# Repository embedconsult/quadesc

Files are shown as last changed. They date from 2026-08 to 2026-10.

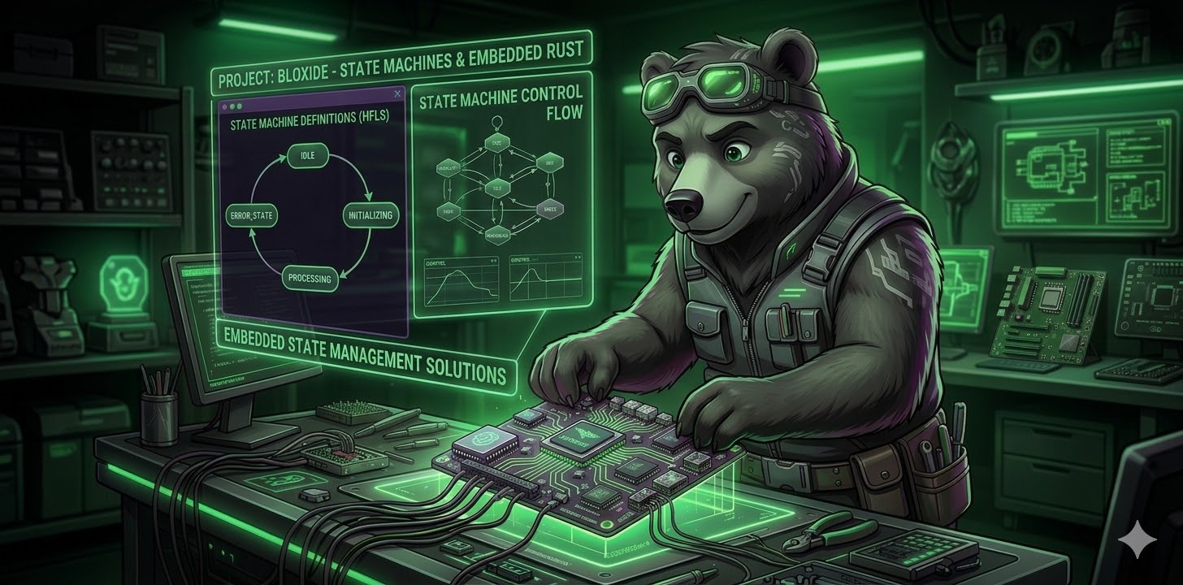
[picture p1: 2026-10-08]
firmware/source/inputs/bloxide/bloxide.jpg

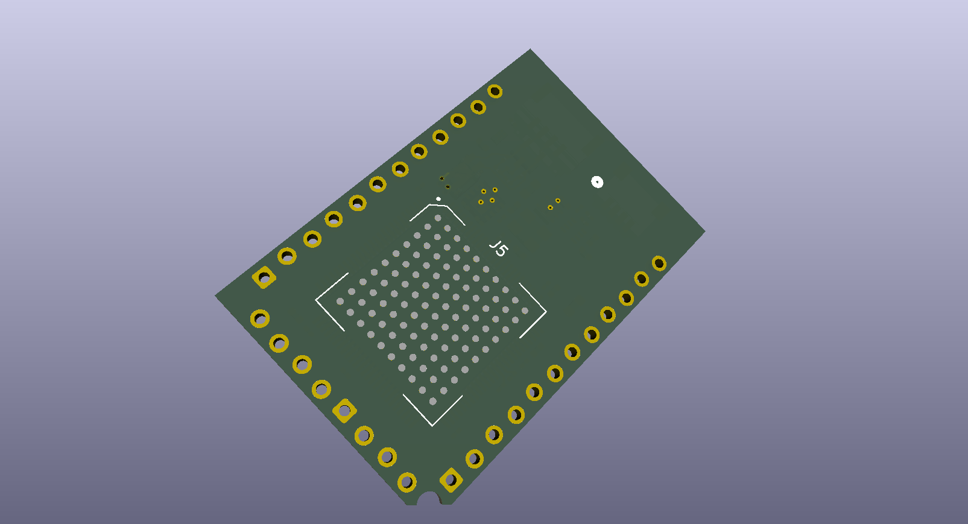
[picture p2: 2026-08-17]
som/som_bottom.png

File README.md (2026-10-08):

# QuadESC

QuadESC is a four-motor power board with an installed AM13E system-on-module. This repository contains the editable mainboard and module designs, schematics, firmware sources and hardware manuals.

## Hardware documentation

The handoff manuals are maintained as Markdown in [`documentation/source/`](documentation/source/):

- [QuadESC manual](documentation/source/quadesc/index.md): power, connections, sensing, control resources and mechanical integration.
- [AM13E SoM manual](documentation/source/som/index.md): module interfaces, pin assignments, power selection, TI BSL programming and debug.

Connector references retain pin numbers, net names and electrical mappings. Use the KiCad designs for physical board geometry.

See [documentation build instructions](documentation/README.md) to generate the HTML site locally. CI builds and checks the same source for merge requests and pull requests, and publishes the manuals from `main` through GitHub Pages on [embedconsult/quadesc](https://github.com/embedconsult/quadesc), with an optional GitLab Pages pipeline for OpenBeagle. Generated HTML is a CI artifact rather than checked-in content.

## Repository layout

| Path | Contents |
| --- | --- |
| `mainboard/` | Editable QuadESC mainboard design |
| `som/` | Editable AM13E module design |
| `mainboard_schematic.pdf`, `som_schematic.pdf` | Exported schematics |
| `documentation/source/` | Markdown manuals, shared diagrams and styling |
| `documentation/reference/` | Electrical connector, GPIO and analog reference data |
| `tools/documentation/` | Documentation build and validation scripts |
| `firmware/` | Firmware sources and existing application/loader artifacts |
| `drone-flasher-swd/` | SWD programming utility |

Documentation builds use only the manuals and their reference assets. See the [programming guide](documentation/source/som/firmware.md) for module programming interfaces.

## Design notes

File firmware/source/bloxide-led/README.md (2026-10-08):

# Bloxide LED host precursor

The separate host XCP demo composes this generated LED Owner with the generated XCP Session. Its additive `XcpProvider` action translates typed requests into the existing sole Owner, retained outcomes and output admission; it does not select Profile P or SAVE. The frozen Apply/Read/Release scalar interface remains intact.

This private feature package contains plain LED messages, validated scalar values, the portable calibration owner action context, a split-once output slot, absolute-time phase calculation, and a pure TOML `led-owner` blox. It reuses the pinned `bloxide-calibration` `Owner`, `CommitGate`, and `OperationKey` source supplied by this diagnostic hub. The local Cargo path dependency is explicit for this bounded composition; a releasable independent package still needs a reviewed source distribution choice.

Only `LedController::apply` changes the active configuration. A changed value reserves the output slot before the T07 owner commits and publishes an `OutputSchedule` before the retained Applied result is visible. A same-value operation does not reserve a slot or reset phase/revision. The split producer and consumer are moved to distinct owners; no actor Reset splits the slot again. `phase_at` computes the current logical phase from an absolute epoch, including late polls and constant duty extremes.

The output slot supports one queued schedule, one service-owned schedule and two retained dispositions. Quiescence closes admission and retires a queued schedule with a disposition; an explicit consumer acknowledgement opens a requested new output epoch. Host tests cover this path. Physical GPIO completion, electrical state, timing and fault recovery remain target integration obligations.

Source files here are authored for this precursor. No license is asserted for this new repository. The framework and calibration inputs retain their own source notices and are not copied into it.

For the hosted diagnostic, a second split-once bounded reply slot passes typed action outcomes to the serial service. An occupied reply remains intact and latches overflow instead of overwriting a result; the serial session stops admission if that invariant fails.

This integration branch adds a selected restricted Profile P action and a UART SAVE action to the same declarative `led-owner` blox. `LedController` still contains the sole calibration `Owner<LedConfig>`. Profile P borrows that Owner only inside the generated action; scalar writes use the existing validated apply path and output reservation. A fixed `ProfileSlot` holds the reviewed protocol/service/Broker state, while the application pumps backend commands outside the action. A host-only simulator supplies media for source tests. Without an attached slot, SAVE is unavailable and Profile P is fenced, including in the selected AM13 target composition. No fault recovery control was added.

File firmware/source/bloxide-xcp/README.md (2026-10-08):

# bloxide-xcp

The drone board composition in `../drone-esc-firmware/examples/am13-xcp-control/system.toml` selects this package's CLI-generated Session actor. Ready/connection/recovery/waiting leaves route packets declaratively, and fixed bridge slots carry owned provider commands and complete responses. The independent S0 packet/core/SxI libraries remain reusable and no generated Rust is edited in source.

Reusable transport-neutral XCP protocol surfaces for Bloxide applications.
The implemented `0.1.0` cut is the deliberately narrow scalar S0 profile:
XCP 1.0/SxI 1.0 identifiers, CTO/DTO 8, little-endian byte addressing, and
only CONNECT, DISCONNECT, GET_STATUS, SYNCH, SET_MTA, UPLOAD, and DOWNLOAD.

This is a scoped interoperability profile, not a full ASAM XCP conformity
claim. DAQ, pages, STIM, programming, security, block mode, discovery, CAN
framing, and A2L IF_DATA are not implemented or advertised.

## Packages

- `xcp-messages`: fixed-size plain packet and provider-completion data.
- `xcp-core`: `no_std`, allocation-free codec/session/map/provider boundary.
- `xcp-sxi`: `no_std`, allocation-free LEN8/CTR8/SUM8 codec, explicit-idle
  parser and bounded Session adapter.
- `blox-ctx-xcp`: synchronous context actions with one retained effect and
  one retained response slot.
- `bloxes/session/blox.toml`: pure declarative broker topology; generated Rust
  remains build output.
- `fixtures/generated-session`: real concrete generated actions and lifecycle/
  correlation/saturation regressions against pinned Bloxide, plus a mock endpoint.
- `fixtures/standalone-consumer`: unrelated thermostat-style downstream
  consumer proving the core has no drone, LED, AM13, runtime, or HAL coupling.
- `fixtures/sxi-endpoint`: host-only real Session/SxI endpoint with a bounded
  deterministic provider fake for PTY qualification.
- `interop`: accepted T10 owned synchronous pyXCP transport plus the T34 product
  endpoint runner. The integrated T10 subtree identity is locked in
  `integration-lock.json`.

The checked virtual map resolves logical addresses to descriptor IDs and
offsets. It never turns a client address into a Rust pointer. DOWNLOAD emits
an owned provider request and responds positively only after the provider
reports the canonical owner outcome as Applied. Retired, stale, lost, or
uncertain outcomes fence the session rather than fabricate a rejection.

See [spec/xcp-s0.md](spec/xcp-s0.md) for exact PDUs and invariants and
[application source overview](../drone-esc-firmware/README.md) for the current integration boundaries.

## SxI ownership and scheduling

Construct the adapter once with `xcp_sxi::with_adapter(|adapter| ...)` and move
it into its owning service inside that scope. Lease lifetimes belong to that
instance; completion consumes the opaque token. Check `lease_is_current` before
bounded emission, then `complete_tx`. Use `lifecycle_fence` for Stop/Reset, retaining
Session truth and resources. There is no clone/default/reconstruction API.

Core `Session::service` returns `ServiceResult` with durable dispatch and per-call
new-fault provenance; SxI uses both to revoke partial input on fresh provider
failure while preserving Busy progress.

Call `service` at bounded control opportunities even under RX/TX pressure; supply
monotonic timestamps to parser polling and pre-arrival feeding. Late suffixes
expire before timestamp refresh at >=20ms. `observe_idle(now, provider)` is the
explicit recovery operation and durably fences clock faults. See
[spec/sxi-s0.md](spec/sxi-s0.md) for the complete scheduler and ownership contract.

## Development

Rust 1.94.0 is pinned by `rust-toolchain.toml`.

```sh
CARGO_BUILD_JOBS=2 cargo test --workspace --locked
CARGO_BUILD_JOBS=2 cargo clippy --workspace --all-targets --locked -- -D warnings
CARGO_BUILD_JOBS=2 cargo check -p xcp-core -p xcp-sxi \
  --target thumbv8m.main-none-eabi --locked
CARGO_BUILD_JOBS=2 cargo test \
  --manifest-path fixtures/standalone-consumer/Cargo.toml --locked
CARGO_BUILD_JOBS=2 cargo test \
  --manifest-path fixtures/generated-session/Cargo.toml --locked
CARGO_BUILD_JOBS=2 cargo build \
  --manifest-path fixtures/sxi-endpoint/Cargo.toml --locked
```

The accepted Bloxide baseline `43c4faa...` can lint the source topology. Its
pre-package code generator requires framework crates and the codegen crate as
local paths inside the consumer workspace, so full external materialization
uses the package/composition work owned by T06. This repository does not copy
framework sources or commit generated Rust to work around that boundary.

Public reference pins used for the selected command/error layouts:

- pyXCP 0.29.18 commit
  [`016cf3e`](https://github.com/christoph2/pyxcp/tree/016cf3e44364e9cd93966d144a39d342578a0391)
- [ASAM XCP public overview](https://www.asam.net/standards/detail/mcd-1-xcp/wiki/)

The retained interoperability fixtures exercise protocol packet ownership and
framing independently of the hardware. Their source contracts do not constitute
electrical UART/CAN timing or ASAM conformance evidence. Current application and
host regression results are recorded in `firmware/build-report.json`.

## Restricted persistence profile P (reusable source)

[spec/profile-p.md](spec/profile-p.md) documents the separate reviewed single-page P adapter, its borrowed Owner/service seam, matched host PTY fixture and remaining generated/target gates. S0 remains unchanged; the P adapter is selected explicitly by composition.

The LED integration branch resolves this crate's path dependencies to the selected local framework `2b4ec83`, calibration `c0a693a` and persistence `5d67c99` inputs. `tools/check_profile_p_inputs.py` checks those local pins and unchanged copied metadata. The firmware's generated owner action supplies Profile P's synchronous `Domain` borrow; this crate still has no second LED owner and its S0 source is unchanged. The application uses its own image identity and concrete board calibration backend; see the customer engineering manual for that integration.

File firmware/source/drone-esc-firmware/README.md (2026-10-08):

# Drone board application source

This is the authored schema 7 application composition for the SoM and QuadESC.
The customer release contains 252 parameters and the CAN XCP demo selected by
[`examples/am13-xcp-control/system.toml`](examples/am13-xcp-control/system.toml).
The generated executable is `can-xcp-control-am13`, targeting
`thumbv8m.main-none-eabi` with the application origin at `0x8000`.

[`mcu-xcp-platform`](mcu-xcp-platform) owns hardware initialization, fixed transport
slots, driver/PWM control, calibration storage and lifecycle shutdown. The LED
owner, XCP Session actor and framework are supplied as local source dependencies.
[`characterization`](characterization) contains the portable driver, PWM, ADC and
thermal contracts; [`host-all-motor-regression`](host-all-motor-regression) tests
the concrete board adapter without operating hardware.

Startup leaves PWM and both enable controls inactive. Raw driver faults for all
four motors interlock bench operation. Failed GPIO-off confirmation exposes
`drv_enable_state_known=0` and fences actuation, SPI, SAVE and reboot; an explicit
disable command can retry in a live session. An uncertain lifecycle completion
fences the transport and requires external safe-off and deliberate recovery.
The engineering manual explains that distinction and the bounded bench workflow.

Build, test and artifact commands run from the handoff root:

```sh
bash tools/firmware/build.sh NEW_BUILD_DIRECTORY
bash tools/firmware/test.sh NEW_TEST_DIRECTORY
python3 -B tools/firmware/verify.py
```

The build uses the shipped locks without resolving newer dependency versions.
Authored Rust, TOML and generator sources are retained here. Generated Rust and
Cargo scaffolding are disposable build outputs; the delivered BIN, AB1, ELF,
A2L and JSON metadata are under [`firmware/application`](../../application).
Calibration storage and loader ABI1 retain their existing layouts. SAVE is
available for persisted LED/ADC calibration fields while shutdown is confirmed.

See the [firmware overview](../../README.md), [portable build instructions](../../../tools/firmware/README.md),
[CAN tools](../../../tools/can/README.md), [engineering manual](../../../documentation/html/engineering/index.html)
and [source provenance](../../source-provenance.json) for the complete customer workflow.

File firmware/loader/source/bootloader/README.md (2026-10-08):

# AM13 CAN-FD bootloader ABI1

Standalone Rust reset loader, hardware-qualified2026-09-25 on the attached SOM.
Evidence and limits are in `notes/can-xcp-bootloader-r1/RESULT.md`. Current reservation32KiB; application origin0x8000, capacity222KiB,
end0x3f800; metadata occupies its own2KiB sector, ending at bank boundary0x40000.
Bank1 remains reserved so the application's existing calibration writes stay in
the opposite flash bank. CAL_A0x78000/CAL_B0x7c000 and their guards are preserved.

`contract.json` specifies transport, memory map, header, commit marker and command
sequence. CPU32MHz SYSOSC; explicit25MHz crystal startup, PLL400MHz/20/2 gives
CAN10MHz;500kbps nominal20tq/80%,2Mbps data5tq/80%, TDC offset4mtq.
MCAN_ICLK16MHz>=MCAN_FCLK10MHz, as required by TI SPRUJF2B27.4.2.
Clock startup is bounded; crystal failure stays in loader with CAN unavailable;
SWD recovery remains available. No oscillator autodetection.

Loader IDs0x710/0x711 CAN-FD+BRS64byte CTO; normal app calibration remains
classic500kbps IDs0x700/0x701. GET_ID0 identifies
`AM13E23019-CANBOOT/0.1.0/ABI1`. Reset with BOOT low, then CONNECT within3seconds;
invalid app stays indefinitely, any CONNECT holds until reset. BOOT high selects
TI ROM, not this loader. No app cooperation is required for reset+connect entry.

Standard XCP PROGRAM commands/opcodes and pyXCP0.29.18 framing were checked
against primary local source. Stop-and-wait only: use `last=True` for PROGRAM.
No DAQ, block transfer, sector info, seed/key, signature, encryption or rollback
protection. CRC detects corruption; it is not authentication. Firmware version
is descriptive. Header board/layout/ABI/length/CRC and vectors are checked.

Header staging must precede erase; metadata is invalidated before application
sectors. Sequential image bytes buffer into16-byte ECC-safe program granules.
PROGRAM count0 verifies full CRC and vectors. PROGRAM_RESET verifies again,
writes header then separate commit marker last, ACKs and resets. SRAM MSP must
be within conservative96KiB range and aligned; Thumb reset PC must lie in image.
RAM flash/read routines avoid instruction fetches from busy flash; GSC ownership,
sector bounds, dynamic protection and status checks guard each operation.
Non-erased/partial metadata reads handle ECC from RAM; invalid CRC cannot boot.
No mass erase, NONMAIN write, fuse/debug lock, static write protection or motor
operation is implemented. Logical bounds exclude loader, metadata and calibration
from raw app programming. Metadata access is a constrained staged transaction.

Application reinitializes its clocks/interrupts. Handoff stops CAN/SysTick, masks
interrupts, disables/clears NVIC, sets VTOR0x8000 and validated MSP/Thumb PC,
clears CONTROL/BASEPRI/FAULTMASK/MSPLIM. IRQs remain masked until app startup.

One-time install is SWD, using checked target identity, sector-only writes and
full loader readback. UART bootstrap was not tested. No factory NONMAIN change
is required by this source. Current SOM still has the earlier ROM bootPLL fix;
a physical untouched-factory NONMAIN test has not been performed. ROM CAN IDs3/4,
1Mbps and its25MHz direct-clock limitation are separate from this custom loader.

CLKDIV must be written after CLKEN; target readback admission checks this.
Normal CAN controller automatic error retry is enabled, with bounded polling.

Build: `bash notes/can-xcp-bootloader-r1/build-loader.sh` and `build-app.sh` on
bloxide1, Rust1.94.0 target thumbv8m.main-none-eabi. `package.sh` produces
bootloader.bin,app.bin,app.ab1. Host tests: test-core.sh and test-driver.sh.
Deployment/updater scripts are under notes/can-xcp-bootloader-r1/hardware;
bootstrap procedure and hardware evidence are packaged separately.

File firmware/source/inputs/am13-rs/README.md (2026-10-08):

# am13-rs

Small all-Rust `no_std` AM13E23019 support extracted from the frozen corrected diagnostic firmware. This is chip support, not a complete PAC, an ESC application, or electrically qualified new firmware. SoM pin assignments live in `esc-som-board`. Current ADC, MCPWM, UC2 I²C, UC3 SPI and MCAN0 additions are described in [board peripheral drivers](spec/board-peripherals.md).

`Peripherals::take()` is a one-shot hardware acquisition that quiesces inherited IRQs. It yields independent clock, GPIO setup, UC4, ADC, MCPWM0–3, UC2 I²C, UC3 SPI, MCAN0 and SysTick owners. Handles remain non-Send/non-Sync and move into a single thread-mode executor; no legacy global MMIO reference or mutable actor backdoor is exposed. Drop never releases the singleton or reinitializes hardware.

Clocks select nominal 32MHz SYSOSC. `Clocks::uc4_hz()` correctly reports 32MHz with the MCLKDIV2 domain bypass; UART uses CLKSEL=8 and CLKDIV=0. `Uc4::configure` prepares 8N1 disabled, the board selects pads, and `enable` verifies readback. `Uart::try_read/try_write/is_tx_complete` do bounded register work; `embassy` adds embedded-io-async Read/Write with 100us timer retries and cancellation-safe single-byte admissions. TX admission waits for the previous byte’s EOT; flush includes the final stop bit and is independent of receive activity. See [TX completion and bounds](spec/uart-completion.md). GPIO outputs implement embedded-hal 1.0.0. Readback is register/pad evidence, never optical observation.

The `embassy` feature provides the real Embassy time driver and sole SysTick handler. It uses a coherent u64 10kHz counter and 16 fixed task/deadline slots. It validates Embassy task wakers and stores TaskRef, so no generic Waker clone/drop or timer allocation occurs. Cancelled timers can leave one earliest pending deadline per task until expiry and cause harmless early wakes. A seventeenth retained task deadline latches `time::capacity_faulted()` and panics; target integration must use an allocation-free halt handler. See [platform contract](spec/platform.md) and [integration obligations](spec/integration.md).

Build/test on Rust 1.94.0:

```sh
CARGO_BUILD_JOBS=4 cargo test --locked --features embassy
CARGO_BUILD_JOBS=4 cargo clippy --locked --all-targets --features embassy -- -D warnings
CARGO_BUILD_JOBS=4 cargo check --locked --target thumbv8m.main-none-eabi --features embassy
```

Set `CARGO_TARGET_DIR` to a job-local directory. The linked target example is in the independent `esc-som-board` consumer. No C SDK runtime, ROM FFI, heap, PLL, SRAM3 configuration, or diagnostic monitor is included. Flash access is described separately in `spec/flash-design/`.

Tests include register faults, ownership, clock/divisor traces, u64 carry, full timer table, cancellation and real Embassy executor first-poll/timeout/expiry/task-cleanup plus async UART. A test instruments all four allocator calls, proves detection by deliberate calls, then observes zero attempts for the selected executor/driver workload. This is x86_64 driver evidence; T36 and full-image T13/T35 remain independent allocation/latency gates.

Source notices/provenance are recorded in [PROVENANCE.md](PROVENANCE.md); no license has been invented. Origin is private.

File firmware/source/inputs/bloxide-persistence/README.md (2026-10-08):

# Bloxide persistence source

This package provides bounded calibration records, dual-record recovery,
immutable save snapshots and an owned-command persistence service. The portable
core and simulator are retained with their technical contracts, regression
vectors and source notices. The drone application's concrete calibration storage
implementation is selected separately by its board composition.

Read the [portable correction API](specs/portable-correction-r1.md),
[record and service contract](specs/record-and-service-v1.md),
[conditional erase/program proof](specs/erase-integrity-proof.md),
[implementation interfaces](specs/implementation-packages.md), and
[test catalogue](tests/test-catalogue.json). The complementary-pair record proof
depends on its explicit monotonicity, ECC and isolation model; portable tests
do not establish those physical assumptions.

[`evidence/r2-vectors`](evidence/r2-vectors) contains required regression inputs.
Compact public-source identities and technical verification summaries remain
under [`evidence`](evidence). Their original revisions scope those results;
the current handoff's build and regression results are in
[`firmware/build-report.json`](../../../build-report.json).

Use the [customer build/test commands](../../../../tools/firmware/README.md) for
the complete pinned source composition. See the [engineering manual](../../../../documentation/html/engineering/index.html)
for application calibration, SAVE, programming, recovery and safety behavior.
Source notices are preserved; no license is inferred for private source.

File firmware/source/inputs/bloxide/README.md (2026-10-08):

# Bloxide framework source

Bloxide provides hierarchical state machines, actor messages, supervision,
capabilities and code generation. This handoff includes the pinned framework
source required by the drone board application and its regression fixtures.
The active application uses static Embassy wiring on the AM13 Cortex-M33.

Authored state topology and wiring live in `blox.toml` and `system.toml` files;
`cargo-blox` materializes Rust crates and application scaffolding as disposable
build outputs. Plain messages and context action functions retain their separate
ownership boundaries. The framework's reusable Tokio and test runtime APIs remain
available in source, with no alternate customer application selected.

Read the [architecture and invariants](spec/README.md),
[layered architecture](spec/architecture/00-layered-architecture.md),
[static wiring](spec/architecture/03-static-wiring.md),
[declarative wiring](spec/architecture/14-declarative-wiring.md),
[generation source of truth](spec/architecture/15-blox-toml-source-of-truth.md),
and [embedded generation](spec/architecture/19-embedded-generation.md).
The [framework API reference](skills/building-with-bloxide/reference.md) gives
the reusable API details; its illustrative snippets are not additional delivered demos.

Use the customer [firmware build/test instructions](../../../../tools/firmware/README.md)
for pinned complete application generation, builds and tests. Framework sources
and local paths are selected by the application workspace and locks. Current
component identity and per-file hashes are in
[`firmware/source-provenance.json`](../../../source-provenance.json).
Existing [MIT license](LICENSE) and source notices are retained.

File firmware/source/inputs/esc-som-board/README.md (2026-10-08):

# esc-som-board

Owned board resources for the standalone AM13E23019 ESC SoM, using current SysConfig v3 pin authority. The original minimal LED-cal constructor establishes inactive enable/PWM GPIO, inactive driver chip selects, PB18 LED off, fault/DShot/BSL inputs, 32MHz SYSOSC and UC4 PA0/PA1 at the application-selected checked baud. It leaves ADC/SPI/I2C/CAN untouched. The explicit [board peripheral profile](spec/board-peripherals.md) adds the current v3 PWM, 30 raw ADC inputs, external DRV8323 SPI, UC2 I²C, MCAN0 and switchable CAN termination resources. It leaves driver enable low and CAN unconfigured for application-controlled startup; `examples/peripheral-resources.rs` links the profile on Cortex-M.

`initialize(Peripherals, uart_baud)` consumes setup once and returns movable `led`, `uart`, `systick`, and immutable `clocks` values. LED is active low; `set_on(true)` writes PB18 low and verifies GPIO/pad readback. `embedded-hal::OutputPin` retains physical-level semantics (`set_low` means LED on). No resource is cloned into services and actor Reset does not reconstruct the board. The future diagnostic integration must supply 19,200 or 38,400 for the earlier candidate example; invalid rates return `StartupError::Uart(Baud)`. Application ownership, calibration and output slots remain in firmware/feature crates.

Clone this private repository beside `am13-rs` at the revision in `source-lock.json`. The explicit path dependency is intentional for the accepted already-fetched composition slice; ordinary Cargo.lock pins external dependencies, and source-lock pins the sibling content. No transitive auto-fetch/codegen functionality is implied.

```sh
CARGO_BUILD_JOBS=2 cargo test --locked
CARGO_BUILD_JOBS=2 cargo build --locked --release --target thumbv8m.main-none-eabi --features firmware --example led-uart
```

The linked example runs actual Embassy timer tasks: a 500ms LED half-period and paced UART echo with bounded work per poll. It is a review/qualification fixture, not final generated LED/XCP firmware and not a historical text monitor. It has no allocator, uses cortex-m-rt Rust startup, 96KiB initial RAM, and 512KiB flash. The build script provides its memory map only to the firmware example; production firmware owns its layout. Set a job-local CARGO_TARGET_DIR.

See [profile](spec/led-profile.md), [timing evidence](spec/timing-evidence.md), [chip integration obligations](../am13-rs/spec/integration.md), and [provenance](PROVENANCE.md). Cross-build and host tests do not establish new electrical/optical or ARM64 execution claims. No devices were operated by this server worker.

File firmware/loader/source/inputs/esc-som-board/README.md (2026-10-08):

# esc-som-board

Owned board resources for the standalone AM13E23019 ESC SoM, using current SysConfig v3 pin authority. This is the minimal LED-cal platform, separate from preserved core0.1.2 diagnostic firmware. The constructor establishes inactive enable/PWM GPIO, inactive driver chip selects, PB18 LED off, fault/DShot/BSL inputs, 32MHz SYSOSC and UC4 PA0/PA1 at the application-selected checked baud. ADC/SPI/I2C/mikroBUS diagnostics are not initialized. CAN/debug pins remain untouched.

`initialize(Peripherals, uart_baud)` consumes setup once and returns movable `led`, `uart`, `systick`, and immutable `clocks` values. LED is active low; `set_on(true)` writes PB18 low and verifies GPIO/pad readback. `embedded-hal::OutputPin` retains physical-level semantics (`set_low` means LED on). No resource is cloned into services and actor Reset does not reconstruct the board. The future diagnostic integration must supply 19,200 or 38,400 for the earlier candidate example; invalid rates return `StartupError::Uart(Baud)`. Application ownership, calibration and output slots remain in firmware/feature crates.

Clone this private repository beside `am13-rs` at the revision in `source-lock.json`. The explicit path dependency is intentional for the accepted already-fetched composition slice; ordinary Cargo.lock pins external dependencies, and source-lock pins the sibling content. No transitive auto-fetch/codegen functionality is implied.

```sh
CARGO_BUILD_JOBS=2 cargo test --locked
CARGO_BUILD_JOBS=2 cargo build --locked --release --target thumbv8m.main-none-eabi --features firmware --example led-uart
```

The linked example runs actual Embassy timer tasks: a 500ms LED half-period and paced UART echo with bounded work per poll. It is a review/qualification fixture, not final generated LED/XCP firmware and not a historical text monitor. It has no allocator, uses cortex-m-rt Rust startup, 96KiB initial RAM, and 512KiB flash. The build script provides its memory map only to the firmware example; production firmware owns its layout. Set a job-local CARGO_TARGET_DIR.

See [profile](spec/led-profile.md), [timing evidence](spec/timing-evidence.md), [chip integration obligations](../am13-rs/spec/integration.md), and [provenance](PROVENANCE.md). Cross-build and host tests do not establish new electrical/optical or ARM64 execution claims. No devices were operated by this server worker.

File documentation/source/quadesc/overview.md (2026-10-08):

# Board overview and motor channels

QuadESC includes four three-phase power stages and an installed AM13E SoM. Each channel has a gate driver, three half bridges, low-side current sensing and divided phase-voltage sensing. The AM13E SoM at J9 supplies the controller and connects these signals to its timers, ADCs and communication peripherals.

The channels are **Motor 1 through Motor 4**. Their phase connections are J2 through J5 respectively. U1–U4 are **DRV8323SRTAR** gate drivers; U5–U16 are **CSD88599Q5DC** half-bridge devices.

## Board views

```{image} ../shared/assets/mainboard-board-top.svg
:alt: QuadESC mainboard top assembly and connector locator
:target: _images/mainboard-board-top.svg
```

```{image} ../shared/assets/mainboard-board-bottom.svg
:alt: QuadESC mainboard underside assembly and connector locator
:target: _images/mainboard-board-bottom.svg
```

Use these assembly views to find connectors and components. Reference labels match the KiCad board files. Select an image for a closer look.

**Top** looks down at F.Cu. **Bottom** looks directly at B.Cu after turning the board left-to-right, keeping the same top edge up. Left and right therefore reverse; the bottom drawing is not a view through the board. Use the [connector pad table](connectors.md) for electrical assignments.

The underside carries J9, the SoM mating footprint, and J1, the two battery terminals. Motor solder terminals are J2 (Motor 1), J3 (Motor 2), J4 (Motor 3) and J5 (Motor 4); each has three electrical pads.

## Major components

| Resource | Component | Purpose |
|---|---|---|
| U1–U4 | DRV8323SRTAR | Gate drive, current-sense amplification and status/register interface |
| U5–U16 | CSD88599Q5DC | Twelve half bridges across four channels |
| U17 | TPS54360BDDAR | Battery-to-carrier buck regulator |
| U18 | TPS7A4701RGWR | Analog supply/reference regulator |
| J1 | Two battery solder terminals | 1: +BATT; 2: GND |
| J2–J5 | Three solder terminals per motor | 1: phase A; 2: phase B; 3: phase C |
| J6 | Eight-pin FC interface | Ground, battery, current, telemetry and four command inputs |
| J7 | ARM/JTAG header | Debug access through the carrier |
| J8 | Two-pin buzzer interface | Buzzer signal and ground |
| J9 | SoM receptacle | 100-pad LGA plus additional physical pads |

Component numbers belong to each board's own schematic. For example, mainboard U2 is a gate driver and SoM U2 is the CAN transceiver. The connector and circuit references in this manual refer to the mainboard unless they explicitly name the SoM.

## What the circuitry enables

PWM from the SoM commands the gate drivers, which switch the half bridges. SPI lets the application configure a driver and read its registers. Current and voltage signals return to the ADCs for feedback, while nFAULT inputs indicate driver faults.

The four drivers have separate chip-select signals but shared enable controls. This makes [channel selection and enable behavior](control.md) useful to understand before trying a motor-control application. The [sensing guide](sensing.md) follows the feedback path and explains how to convert readings into useful units.

## System boundary

For reusable controller features—UART, CAN, power selection, programming and recovery—use the <a href="../som/index.html">SoM manual</a>. For the battery, motor leads and FC harness, start with this manual's [connection guide](connections.md).

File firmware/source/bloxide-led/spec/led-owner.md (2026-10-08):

# LED owner output fault refinement

## Restored boot intent

For every valid restored `LedConfig`, the one Owner's initial readback and the primed output schedule derive `commanded_on` from `duty_permille != 0`. Duty zero boots commanded off and duty 1000 boots commanded on. Construction leaves revision zero and one initial phase epoch; it does not publish a second schedule or apply a synthetic write. Generated Start/Read must report the same intent as the primed schedule.

The generated owner keeps one canonical calibration state and one retained software outcome. A changed Apply reserves the fixed output slot before committing, then publishes the complete schedule. A same-value Apply does not reserve, increment the revision or restart phase.

The output service reports successful installation through the two-entry completion FIFO. On a readback failure during installation, it reports `Faulted(schedule)` in the reserved completion entry and latches `OutputFault { schedule, Installation, Pending }`. On a later edge failure, the earlier installation disposition remains valid and the latch records `OutputFault { schedule, Edge, Pending }`. Both paths close changed-output admission before the service attempts inactive output. The service records `Verified` only when the inactive readback succeeds; otherwise it records `Unknown`. The fault latch stays readable until explicit acknowledged resume; queued work stays fixed until a completion entry is available for truthful retirement. No physical result rewrites the earlier software Applied outcome.

On a latched fault, the consumer may retire a queued Ready schedule through the existing quiesce operation while admission stays Faulted. It places `CancelledByLifecycle` with B's complete key in the two-entry FIFO only when capacity exists; otherwise Ready remains intact until the producer drains a completion. A previously installed A stays `Installed`, with its later edge fault separately latched. The consumer repeats bounded retirement polls after a fault. No queued command is installed during this period. The producer may explicitly request quiesce from Faulted, drain both dispositions, and acknowledge the fault only after the queued and in-flight work is gone and inactive output has verified readback. The service acknowledges Quiesced only after that fault acknowledgement, an independently confirmed inactive output, and an empty completion FIFO. A requested new output epoch remains closed until the service explicitly accepts resume. Accepting resume clears the acknowledged old fault; it does not retry old schedules or reset/reacquire a device. Unknown safe-off cannot be acknowledged or resumed.

The status reader is read-only and shares the same one-shot split slot. Fixed status exposes the queued schedule, both pending terminal dispositions, and the last drained disposition so exact operation keys remain reconcilable across the FIFO boundary. It has no raw actor access, calibration copy, HAL type, executor handle or heap storage. It reports readback state, never optical observation. Software `Applied`, revision and phase remain owned by the calibration Owner and never change because of physical retirement.
# UART SAVE status action (2026-09-25)

The existing Owner accepts `Save` and the selected portable service owns
backend commands. `ResolveSave(key)` reports a separate terminal durable
record sequence and historical saved revision. The profile slot retains the
exact UART outcome before the existing profile observer releases its service
and broker custody. Pending, failed, indeterminate, rejected, stale and
unavailable are distinct. A request receipt cannot stand in for durable
completion. `ReadSaved` returns the selected portable record's sequence,
source epoch/revision and values; `NoRecord` does not claim empty media.
No second settings owner or persistence library is introduced.

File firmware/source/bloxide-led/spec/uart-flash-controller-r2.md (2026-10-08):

# Target ProfileSlot boundary r2

A target adapter may attach the existing `ProfileSlot` once before the generated Owner starts. The slot owns the portable service/Broker; the Owner alone captures active scalars. The target backend pump owns no mutable Owner reference, takes one service command at a time and completes by exact full header. Terminal UART SAVE status follows the service outcome after ownership settlement. Logical Reset fences/quiesces pending backend work and does not reconstruct the slot or mint epochs.

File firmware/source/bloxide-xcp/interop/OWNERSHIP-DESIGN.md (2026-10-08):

# S0 serial transaction ownership (R3, before implementation)

## Source ordering and rejected design

Pinned pyXCP 016cf3e BaseTransport._request_internal takes command_lock, builds
with upstream XcpFraming, feeds CMD under policy_lock, releases that lock, calls
send, then get. SxI.send invokes the supplied serial.write. SxI._frame_listen
reads and calls the C++ receiver, whose callback queues a frame; SxI.listen
passes it to process_response. BaseTransport.process_response appends resQueue
and notifies its condition before taking policy_lock for RESPONSE. get pops
resQueue and _request_internal removes PID before Master.connect/getStatus
parse. Thus a policy record is neither a transmission receipt nor a consumption
receipt. Retaining or adding observer queues cannot establish the required
ownership. Fresh baseline artifacts reproduce all four false associations and
identity access after invalid status, with zero DOWNLOAD in that workflow.

## Owned seam and linearization

Register S0SerialTransport as a direct BaseTransport subclass: upstream
available_transports/create_transport discover it without assignments or patches.
Master still calls the unchanged BaseTransport request/error path and parses
its returned bytes. Encoding uses unchanged XcpFraming. Receive dispatch uses
the pinned get_receiver_class for LEN8/CTR8/SUM8, synchronously. No SxI listener,
frame queue, resQueue consumption, policy correlation or historical PDU lookup
is involved. This is an explicitly owned serial transport, not a claim that the
upstream asynchronous SxI transport has been fixed.

One reentrant transaction lock encloses the inherited request and get, with a
scoped receipt enclosing the Master method plus named-field checks. All ordinary
requests use the same lock; concurrent exact assertions cannot exchange receipts.
A nested command in a capture callback is refused and fences the transaction.
One immutable request/PDU/counter receipt belongs to this call only. get returns
that receipt's exact response bytes; inherited request removes PID and Master
parses that same byte string. Exact CONNECT/GET_STATUS checks run in get before
Master can parse or return an invalid handshake. Named-field assertions run in
the same receipt scope. No success receipt is retained as a global last response.

send records attempted TX, then immediately checks for waiting input after all
capture callbacks, immediately before calling serial.write. Any waiting input
fences rather than flushes/reassigns it. A full write is required. While get
waits, it alone reads serial input into one bounded frame buffer, checks length,
refuses bytes beyond the sole frame (even a partial next frame), calls upstream
checksum/dispatch synchronously, then checks remaining port input before returning.
The callback fills one local slot, never an independent queue. Unexpected PID,
malformed input, duplicate, pending input, I/O failure or timeout is terminal.
No partial frame survives to another transaction. A valid negative command
response remains a normal XcpResponseError and does not itself fence S0.

Close signals cancellation before waiting for the transaction lock; bounded
reads observe it, refuse publication and release ownership before port close.
Timeout cannot be cleared by getStatus, synch or reconnect on the same instance.
Successful DISCONNECT terminates the instance after returning its receipt.
Recovery means a new serial open/transport/receiver and a new CONNECT/GET_STATUS;
old objects and receipts cannot be reused. Raw disconnected-target ignore tests
must use a separate raw probe, not revive the terminated transport.

## Limits and disconfirming proof

The serial API cannot atomically order a remote emission with local write. Input
already visible at the pre-write check is known stale and refused. A byte-identical
delayed response arriving after the final check or after a clean write may be
indistinguishable; neither CTR equality nor an arbitrary quiet delay solves that.
Any extra bytes actually observed before return or a later write fence the
session. No hidden observer backlog exists. S0 excludes unsolicited DAQ/events,
block and pipelined traffic; those receive no fallback path to an upstream FIFO.

A hub-only prototype must first pass real PTY runs through unchanged Master and
BaseTransport: pre-write unsolicited valid CONNECT/status with invalid actual
response; stale invalid input then good actual response; external handshake gate
(no identity commands); fragmented good replies, coalesced duplicate/partial,
timeout then refused command, concurrent close and fresh reopen. Trace inherited
_request_internal's returned bytes and compare to the sole receipt and parsed
fields. Preserve original failed behavior and prototype source/hash/results.
Only after this proof may product code change. Later final tests repeat the
affected ordering requirements and full delivered regression, metadata/identity,
reference/external PTY and pinned-source/lock checks. Independent review remains
mandatory; this design does not accept T10 or actual T34 endpoint/native/HIL.

## Prototype result before product changes

Hub reproducers/prove_boundary.py with prototype_transport.py passed (exit0,
2.57s) in artifacts/prototype-proof-corrected: four CONNECT/status pre-write and
already-queued cases refused with no new wire command; identity followups were
fenced; fragmented response CTR145 was accepted and the traced inherited request
return equaled receipt.response_pdu[1:]; duplicate and partial-extra refused;
timeout and concurrent close refused further commands; fresh reopen passed.
No product Python files had changed at that point. Prototype source, test source,
result hashes and failed setup diagnosis are retained in the remediation hub.
The first failed proof was a test setup error: after refused CONNECT, Master's
DWORD_pack is uninitialized, so the followup uses the actual transport SET_MTA
request directly. Status cases still call the real identity workflow.

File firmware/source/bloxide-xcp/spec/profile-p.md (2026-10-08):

# Restricted profile P host adapter (T17-I6)

This is the reviewed D1/D2 application profile for a matched, dedicated UART LED client. It is additive to immutable S0. S0 `Session` still returns FE20 for all F9 packets. No generic XCP conformance, MCU image, flash qualification, or physical UART result follows from this host adapter.

## Boundaries and source pins

`xcp-profile-p` owns one P protocol session, PAG/F9/status, the 640-byte retained view and 128-byte identity block, four fixed read latches, and reconnect fences. It borrows the T07 `Owner` through `Domain<V>` and the actual `PersistenceService<S>` and `Broker<4>`. `Domain::write_scalar` must call the existing validated Owner apply path. The profile never stores or mutates a second LED state. The application supplies disarmed/maintenance/schema policy, the selected P identity and addresses, and backend/transport drain facts. The external async pump calls `take_command` and `complete_backend` with owned commands/completions outside HSM actions. Logical Reset calls `logical_reset` on the same retained instance; boot creates a new instance after R3 recovery and Owner initialization.

Exact reviewed source is persistence `5d67c9977c94ab74edde4821f5f880fe15ed65ac` (tree `da668f8949691982b4053654582113b192eb52cf`) and calibration `c0a693a8811d920d05850cfc2ebcfd7956a2741b`. The root Cargo manifest uses their reviewed local paths under this swarm layout; `tools/check_profile_p_inputs.py` verifies heads, clean tracked state and byte-identical copied metadata. T34 T08/T10/framework pins remain in `integration-lock.json`. No independent Git acquisition claim is made.

`ProfileP::new` checks identity layout and rejects absent/uniform synthetic hashes. The dedicated client additionally verifies the actual image, parsed A2L, descriptor and policy hashes before any E6/F9 or DOWNLOAD. The host fixture loads an acyclic identity at process startup from a separate file generated from the compiled host executable and exact fixture inputs. It is marked `host_fixture_only`; production admission refuses it. MCU composition must generate its own identity from the final image and metadata after final address allocation and bind it through the same checks.

## Save and readback

F9 is exactly `F9 01 00 00`; the sole page must have FREEZE explicitly selected. Known policy/schema/write-lock/deadline refusals precede reserve/capture/save. Accepted C is copied from `capture_owner` before the one FF, and backend progress is observed later through the real service. `observe` records an exact settled terminal in Broker before service/Broker release; unsettled Indeterminate keeps custody. A staged ambiguous result keeps its key and snapshot separately from the previous accepted summary and fences the wire until `reconcile_staged`. For internal clients 1–3, `retain_client_capture` stages one candidate in that same fixed scratch; the application calls service `save` and then `finish_client_save` in the same serialized turn. Only exact Accepted or fast Durable admission replaces the accepted summary. Exact rejected admission retires its service/Broker key and preserves the predecessor key, C and result. Failures leave the originating connection's request bit set, with no event or second F9 response. A diagnostic reconnect requires the application to supply all true idle/drain facts, remains read-only, and needs a new CONNECT. E6 and EB selection controls refuse with FE27 after their existing validation; E5 and readback remain available, while F9 and DOWNLOAD remain denied. Normal namespace advance performs checked exact +1 and both Broker/service handshakes; partial failure stays fenced.

The 640-byte view follows the approved offsets and distinguishes retained C, current durable record and live Owner RAM. The wire client latches at `SET_MTA(0x10000)`, seeks within the same latch and reads sequential 1..7-byte chunks. Other three clients have separate fixed latches and cursors. Errors leave cursor unchanged; exact-end retires a latch. The immutable identity is at `0x10400`. Fixture addresses must be replaced only by reviewed composition. No record/schema or portable R1–R9 API was changed.

## Host verification and remaining gates

The actual SxI Parser/Encoder host example drives the actual persistence service and bounded simulator through PTY. `interop/tools/profile_p_pty.py` runs unchanged pinned pyXCP/pya2ldb in a dedicated process, sets public `General.disable_error_handling=True`, parses the copied A2L, checks the matched host identity before writes, and records raw/decoded exchanges. The P transport preserves sequential response ownership and accepts dynamic GET_STATUS; S0's transport is unchanged. The host bundle is not a production image. C21-C23 host subsets and unmet target obligations are recorded in the job hub RESULT.md. Generated Bloxide composition, target allocation, full image fit, native/MCU build, physical UART, and boot/power-cycle restore remain I5/T36/T16/T18 work under their owners.

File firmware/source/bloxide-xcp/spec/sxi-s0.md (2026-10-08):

# SxI scalar S0 transport design

Status: T34 local implementation design, subordinate to immutable
`led-xcp/0.1.0`. It does not revise the accepted profile.

## Wire format

Each frame is exactly `LEN:u8 | CTR:u8 | PDU[LEN] | SUM:u8`, where `LEN` is
1..8 and `SUM` is the low eight bits of `LEN + CTR + every PDU byte`. There is
no padding, delimiter, sync byte, byte-order option, escaping, or in-band scan
for a plausible header. The maximum frame occupies 11 bytes.

Each direction owns its own transmit counter, initially zero and incremented
modulo 256 only when an encoded frame is produced. A receiver records the first
counter and diagnoses subsequent repeats or gaps relative to the expected
modulo-256 value. It still admits an otherwise valid frame. CTR is never echoed,
never compared across directions, and never used as an XCP request identity.

SUM8 catches only some corruptions. A checksum pass is not proof of an
uncorrupted physical transfer and this profile is not a motor safety mechanism.

## Parser and time contract

The parser owns one `[u8; 11]`, a byte count, an optional expected frame length,
the last observed byte timestamp, and counter diagnostics. It has two modes:

- `Accepting`: a fresh LEN begins a frame; one completed valid frame is returned
  directly to the caller before any later coalesced byte is consumed.
- `DiscardUntilIdle`: all bytes are dropped and update the last-byte timestamp.
  Only an explicit idle observation can return to `Accepting`.

LEN0/LEN9, checksum failure, UART framing/overrun/parity indication, incomplete
frame expiry, timestamp regression, and caller overflow enter
`DiscardUntilIdle`. None yields a PDU. A checksum failure consumes its declared
frame then still requires idle; bytes following it in the same batch are not
scanned as headers.

The injected time domain is monotonic microseconds. `observe_idle(now)` proves
idle only when `now >= last_byte` and `now - last_byte >= 20_000`; equality is
expired. `now < last_byte` is clock regression/overflow and remains discarded
until a later representable observed-idle interval. `poll(now)` on an incomplete
frame uses the same comparison and enters discard at exactly 20,000 us. `feed_byte` checks that same expiry BEFORE replacing the arrival timestamp,
so a late suffix is discarded even without a preceding poll. The arriving byte
then starts the next observed-idle interval. Arrival never implicitly recovers
or establishes a fresh header; only explicit `observe_idle` can do that.
The adapter's `observe_idle(now, provider)` durably fences Session and TX on
clock regression, including wrapping from u64::MAX to zero.

## Bounded adapter

The adapter owns the parser, one complete RX PDU slot, one complete encoded TX
frame slot, a sender counter, and diagnostics. It wraps an existing T08 Session,
VirtualMap and ProviderPort by reference/ownership chosen by the composition;
it does not replicate XCP semantics.

One public service step performs bounded work. Control (`Session::service` and
provider completion) receives priority over accepting another RX PDU. At most
one PDU is admitted to Session and at most one response is encoded per step.
When RX is full, additional complete input is rejected into discard-until-idle;
there is no unbounded byte or packet queue. When TX is full, no next command is
admitted. A response counter advances only when the response frame is admitted
to the owned TX slot.

TX ownership states are `Empty`, `Ready(frame)` and `InFlight(send)`.
`with_adapter(|adapter| ...)` initializes one owned adapter with a fresh invariant
lifetime brand. Move it into the service/context inside this scope at startup;
the brand and leases cannot escape or cross into another adapter scope. There is
no public new/default/clone/copy, no global registry, pointer identity or instance
integer. Instance collision/wrap/exhaustion is structurally unrepresentable.
Logical Stop/Reset uses `lifecycle_fence` on the same adapter and Session; it must
never reconstruct resources or discard outstanding owner truth.

`take_tx` moves out an opaque, non-Clone/non-Copy `TxLease` with the owning brand
and a private nonwrapping u64 send sequence. `frame()` borrows immutable bytes;
the platform checks `lease_is_current` immediately before each bounded emission
and consumes the token with `complete_tx` when finished. Fences invalidate an
in-flight token, which can still be returned but cannot complete a later send.
A consumed token cannot be used for delayed duplicate completion. Copying bytes
is not copying send authority. Driver cancellation/draining of already admitted
hardware bytes remains a platform obligation before reconnect.

Send sequence is reserved when a response enters TX. Its exhaustion and transport
epoch exhaustion are terminal for RX/TX admission; neither wraps nor resets on
logical lifecycle. Session control/completions still reconcile retained work.
Wire CTR remains an independent modulo-256 diagnostic counter.

Every service call first drives one bounded Session control/deadline/retry step,
even with queued RX, taken TX or a partial frame. Session returns `ServiceResult`:
`dispatch` carries durable delivery state and `new_fault` identifies Unavailable
observed during this particular release/ResolveOrCancel attempt. A fresh fault
invalidates the partial/RX/TX boundary and epoch once even when an older fence
was already handled. Busy, successful retry, confirmed admission and no-work
reports do not constitute fresh faults. Repeated unchanged durable reports must
preserve the recovered boundary. A newly admitted CONNECT re-arms durable-fence
tracking. No transport_lost call is repeated from this service path, so a service
fault does not trigger another owner attempt. At most one RX PDU follows control.

The provenance is a local return value, not a stored flag, counter or sequence.
Every actual Unavailable attempt is a fresh fault; no identity can wrap or alias.
Logical Reset preserves all existing ownership and checked identity state. After
a new release fault at20402us, partial CONNECT0200ff from20401us is discarded;
matching Released then suffix0001 cannot synchronize without another explicit
idle boundary. Busy at20402us preserves the partial CONNECT and progress.

The fence never clears the T08 provider effect, pending write, retained outcome,
operation key, or retirement. Byte recovery proves no mutation result. The
adapter does not manufacture Busy, rejection, Ready, Released or readback.

## Host endpoint

The T34 endpoint is a host executable using the actual public Session and this
adapter with a fixed-capacity deterministic provider. It receives raw bytes from
a PTY, supplies monotonic timestamps, polls on 10ms select timeouts and immediately
before each arriving chunk at its arrival timestamp, and emits only a current
send. Idle recovery is an explicit harness operation after observed quiet;
periodic polling never automatically calls observe_idle. The OS scheduling
interval is not a hard real-time guarantee; pre-arrival expiry is authoritative. It records raw reads/writes,
parser dispositions, Session admission, provider commands/completions and the
specific command/response association consumed by the pinned client.

The endpoint supports forced malformed input and response-backpressure schedules
for tests. Recovery stops requests, closes/discards the host client and parser,
observes at least 50 ms of quiet (therefore crossing the target's 20 ms boundary),
creates a fresh client transport, CONNECTs, and performs fresh readback. It never
blindly retries a timed-out DOWNLOAD.

This endpoint's provider is explicitly a qualification fake. Production T07/LED
ownership and platform UART binding remain T11/T35 work.

## Versioned serial profiles

- `reviewed-19200-8n1`: selected external diagnostic baseline, 19200 baud, 8
  data bits, no parity, one stop bit, full duplex, LEN8/CTR8/SUM8, no escaping.
- `reference-pty-38400-8n1`: historical candidate retained for T10 fixture
  reproducibility only.

A PTY does not measure or qualify electrical baud, modem control, reset/BSL
interaction, native ARM64, target timer accuracy, or physical reliability.

## Correction test equivalence

The original normative assertions are identified by source revision `0e55ab84`.
API adaptation does not treat compilation failure alone as proof of runtime
fencing; the retained tests assert the runtime behavior directly.

| Historical normative assertion | Corrected equivalent |
|---|---|
| F1 arrival_at_deadline | Same runtime assertion in review_adversarial; no pre-poll required |
| F1 all_splits_exact_arrival_deadlines | Same 19999/20000/20001 schedules in review_extended; additional adapter zero-provider-admission test |
| F1 actual30/80ms witnesses | verify_pty_deadline.py asserts zero response/backend admission and no in-band recovery; fresh CONNECT only after explicit idle |
| F2 taken response idle regression | Same genuine token/current check; observe_idle now takes the real provider |
| F2 queued response idle regression | Same no-take assertion |
| F2 pending write/u64 wrap | Same full-key ResolveOrCancel; added Applied/outcome/actual Released and reset retention |
| F3 100 RX opportunities | Same release retry schedule; no fabricated Released |
| F3 100 held TX opportunities | Same release retry schedule with a live genuine token |
| F3 partial frame owner deadline10300us | Same ResolveOrCancel assertion at the exact owner deadline |
| F3 original worker run2 partial boundary | Delivered truncation test plus repeated durable fence/service schedule retaining all3 bytes until exact expiry |
| F4 completed prior send becomes current | Consumed-token use is compiler-rejected; runtime fenced old token remains false across a fresh send |
| F4 cross-instance lease | Nested brand current-check/completion and prior-scope escape are compiler-rejected, even with send1 in both instances |
| F4 delayed duplicate completion clears current | Compiler rejects second completion of consumed token; real unconsumed old fenced completion returns false and preserves the newer genuine token |
| F4 Adapter Copy | Copy and Clone compiler rejection; runtime ownership move preserves genuine token semantics |
| F4 forged public lease | Private-field construction compiler rejection |
| F4 identity exhaustion | Runtime final-send/terminal send exhaustion and epoch exhaustion, including retained Applied/release; instance integer exhaustion cannot occur because there is no finite instance namespace, with cross-scope/escape/reconstruction compiler tests |

Rust compiler tests are executable rustdoc examples in src/ownership.md. The
library runtime tests preserve all17 delivered tests and add the unchanged
positive arithmetic/coalescing/overflow review schedules. The accepted Session
lifecycle fixture is generated from TOML with pinned codegen, never hand-edited.

## Remaining integration obligation I1

The generative scope is unchanged. A concrete initialized-once selected-executor
binding must place the owned service/future within that scope and prove its
post-freeze lifetime and Reset behavior. A scoped host positive does not prove a
static runtime binding. T11/T36 retain this unresolved obligation.

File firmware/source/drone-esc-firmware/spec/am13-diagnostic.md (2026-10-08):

# AM13 generated diagnostic composition

## Selected host simulated-media boot

The `uart-persistent` and `xcp-p` host adapters may name one strict raw fixture containing exactly two 1024-byte simulated slots. Startup rejects a missing or wrong-size fixture. It classifies both slots with the pinned portable classifier, recovers one selection/health policy, and constructs the generated actor's sole `LedController` from that selected configuration. The same `Recovery` initializes the attached persistence service before Start. The fixture is a serialization of the simulator's media after backend commands, not a second active settings store or an embedded persistence protocol. Its contents can be copied between host endpoint processes for a simulated restart. Corrupt, unsupported and interrupted bytes follow the reviewed classifier defaults and write policy; no physical recovery authorization is inferred. Without a fixture, selected host behavior starts with empty simulated media. Target boot remains defaults and target SAVE remains unavailable.

`examples/am13-xcp-control/system.toml` selects the existing `led::led-owner` actor and Embassy runtime. Platform construction consumes AM13 T05 peripherals once, configures inactive motor outputs, the dedicated active-low LED and UC4 at the current 19,200 8N1 diagnostic basis, and retains the sole SysTick. The output service exclusively consumes the split schedule slot and owns the LED; the UART service exclusively owns UC4, a 64-byte line buffer and a reply reader. Both services are spawned before `freeze`; they first poll only after the generated setup returns. The sole actor owns T07 state. Reset/Stop never reacquires peripherals.

Plain `GET`, `SET PERIOD <u16>`, `SET DUTY <u16>`, `SAVE`, `STATUS` translate to the existing Read/Apply/Release typed seam. A mutation uses one operation key, waits for a correlated retained terminal outcome, releases it and only then advances the sequence. A rejected pre-send leaves the key reusable; admitted but uncorrelated or timed-out requests close the session as uncertain. `SAVE` returns unavailable. Output acceptance is software scheduling, not optical proof.

The process-wide startup arena freezes irreversibly at generated `platform.freeze`, before actor first poll/Start, UART admission and SysTick interrupt enable. Every GlobalAlloc entry checks the flag, increments its own fixed counter on a forbidden attempt, and halts without formatting. High-water and counters are retained in statics. A cross-build proves only compilation/linkage and the fixed memory envelope; host generated-runtime child-process qualification must observe real first polling, messages, timer and cleanup. General resolver confinement, physical behavior, persistence, XCP and complete T36/T13 coverage remain unproved.

## AM13 correction: faults and transport bounds

The output consumer latches an installation or edge readback failure against the exact published schedule. Installation failure also occupies the completion reserved at take. Fault closes output admission immediately. The service then attempts inactive LED output and records verified readback or unknown physical state if that attempt fails. The software Applied result and revision remain unchanged. STATUS reports the bounded latch and allocator counters; readback is electrical evidence, never optical evidence. A same-value Apply does not reserve an output slot or change phase/revision.

After either fault, the LED service repeatedly polls the portable fault-retirement operation. It cancels any queued Applied schedule with its exact key only when completion capacity exists; full FIFO retains the queue until owner draining. It does not reopen admission or retry an installed schedule. Diagnostic STATUS reports queued, pending-terminal and last-drained exact keys and the separate installed-command fault. Coordinated fault acknowledgement and new-epoch resume require owner drain, verified inactive output and explicit control; the diagnostic itself does not request recovery. Unknown safe-off keeps recovery closed.

The generated Embassy host qualifier's installation-fault case moves an owned `esc-som-board::Led` backed by a fixed register model into its LED service, forces its pad readback to fail after the first changed Apply, and runs both failed installation and failed safe-off through that board API after freeze. A separate generated case holds A installed while B commits, injects A's later edge readback fault, and observes B's exact-key cancellation and retained software readback. Its four-operation allocator guard covers those calls and the generated owner actions. This remains a hosted time-driver and register-model observation, not a target IRQ or physical LED observation.

The UART service permits at most 400 ms per complete response write/flush, measured by the selected monotonic Embassy timebase. At 19,200 8N1, the 640-byte fixed response capacity needs about 333 ms on an uncongested wire; 400 ms exceeds that serialization budget. A timeout ends the session because some bytes may already have left UC4. When a mutation has been admitted and its response cannot be delivered, retain and report its exact key as uncertain; never translate it to Rejected. The owner result is released only after a complete response flush, then its fence is acknowledged before the next command. The owner wait remains five seconds (request expiry six seconds). Every synchronous RX error clears the partial line and awaits one millisecond, so repeated errors cannot monopolize the executor. A fixed counter saturates and is visible through STATUS when UART remains usable.
# UART flash SAVE source state (2026-09-25)

`SAVE` enters the same generated LED Owner as SET/GET. The UART translator
waits for the portable terminal outcome after an accepted receipt. It reports
`OK durable` only for `Outcome::Durable` after exact service readback; timeout
reports a pending key and preserves uncertainty. The target currently has no
qualified boot slot reader, controller pump or durable external wear authority,
so it does not attach a persistence service and returns `ERR save-unavailable`.
`GET` asks the same Owner for active values and a separate selected durable
record view. An unattached target says `saved=unavailable`; a service with no
selected record says `saved=no-record`, without guessing whether media is empty.
The retained flash handle is constructed once and moved to the UART service;
logical reset never acquires another. The linker limits all load bytes to
bank0 and names the bank1 settings regions. This is source preparation, not a
write-enabled image or device result.
The UART service captures the chip's read-only flash observation once after
startup. `STATUS` reports only its necessary `flash_basic` result; the bounded
read-only `FLASH` request reports the raw factory/FRI/status/protection words.
Keeping these responses separate preserves the 640-byte UART bound even when
STATUS contains all exact schedule identities.
Its `flash_basic` field is a necessary check only; it does not permit media
reads, erase or program and requires independent read-only device review.

To activate: independently review read/ECC and controller idle/protection
evidence, 32 MHz FRI RWAIT>=1, flash execution closure, bounded deadlines and
external durable wear receipt; construct one service from both classified
2048-byte slots and pass its selected record to `LedController::new_with_config`.
Use the fixed UART SAVE receipt/ResolveSave action and pump each backend command
outside the HSM. Preserve the default/corrupt/unsupported classification.

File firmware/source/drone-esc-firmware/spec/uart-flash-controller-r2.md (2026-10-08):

# Conditional target UART SAVE composition

The generated `led-owner` retains the only calibration Owner and one `ProfileSlot`. Startup classifies both reserved MAIN slots only after healthy ECC-aware reads and checked mapping; the same recovered config primes LED output and service. The backend pump takes fixed commands from the service, preserves full headers and original absolute deadlines, and reports only observed completion. A reset requests quiesce and retains the flash handle; it does not mint a lease. UART receipt is separate from durable terminal resolution.

No lease or inventory history is available on this server. Unknown history means zero authority. Target startup therefore remains read-only and SAVE reports denial until the fixture provides a durable lease/intent/receipt store and the controller admission predicates. No target operation is authorized by this spec.

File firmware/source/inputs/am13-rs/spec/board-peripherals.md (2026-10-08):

# Board peripheral chip support

These are bounded polling drivers with exclusive handles from `Peripherals::take`. They use 32 MHz SYSOSC/MCLK except MCAN, which explicitly starts the 25 MHz XTAL HFCLK and selects it as CANCLK. No driver allocates. `RegisterIo::wait` is bounded to 100,000 reads; I2C and CAN use similarly bounded foreground loops. The caller owns task scheduling and electrical validation.

| Driver | Register source | Scope |
|---|---|---|
| `pwm::McPwms` | SDK `hw_mcpwm.h`, `dl_mcpwm.h` | MCPWM0–3, one shared frequency per module, six output selectors, duty/high width, continuous start and forced-low stop. Tick/divider quantization returned. MCPWM offers action-qualifier one-shot **force level**, not an exact one-pulse waveform or N-period train. Exact finite trains would require a separate event/interrupt mechanism with verified latency, so no finite-count API is exposed. |
| `adc::Adcs` | SDK `dl_adc`, `hw_adc.h`; corrected diagnostic `chip/adc.rs` | Three ADCs, preserved ROM trim (power only, no reset), 16 MHz ADCCLK, external board reference, SOC0/SEQ4, 448-cycle sample window, raw 12-bit sequential conversion. Timeout is explicit. |
| `spi::Uc3` | SDK `hw_unicommspi.h`, `dl_unicommspi.h`; corrected diagnostic UC3 setup | 100 kHz mode 1, 16-bit MSB-first full-duplex word. Chip-select ownership is board-level. DRV8323 framing uses its TI datasheet: read bit 15, four address bits 14..11 and 11 data bits. |
| `i2c::Uc2` | SDK `hw_unicommi2cc.h`, `dl_unicommi2cc.h` | 100 kHz 7-bit controller, 1..4095 byte write/read and write-then-read repeated START, NACK/arbitration/error/timeout reporting. UC2 is the SDK's advanced-feature instance. External pull-ups and target response still require a bench check. |
| `can::Mcan0` | SDK `hw_mcan.h`, `dl_mcan.c`, `hw_sysctl.h`, `dl_sysctl.c`; TI AM13E230x TRM clock tree | 125/250/500 kbps nominal from 25 MHz XTAL; classic standard-ID data frames, one RX FIFO0 element and one dedicated TX buffer, 8-byte payloads. No CAN-FD, extended ID, remote frame or protocol stack. TX completion is polled and cancellation requested on timeout. Board transceiver and XTAL operation are unverified electrically. |

The local SDK copy is register and sequence reference; no TI source was copied into the Rust files. The SDK's existing notices stay with those source files. The board pin authority is the current v3 SysConfig export in the companion crate, rather than historical spec tables.

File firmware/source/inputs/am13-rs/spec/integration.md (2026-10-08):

# T06 / T13 integration handoff

Consume am13-rs and esc-som-board as platform implementation libraries. No HAL type belongs in a message, portable context or blox. The mailbox-free LED output service receives the moved `Led` GPIO plus its feature-owned output-slot consumer. The owner keeps the portable producer; T05 does not reinterpret Applied/Ready/epoch/quiesce/revision/retirement semantics.

1. Select Rust1.94.0, thumbv8m.main-none-eabi soft float; cortex-m-rt0.7.6 (`set-sp`, `set-vtor`, `zero-init-ram`). Firmware owns `memory.x`: initial RAM 0x20000000+96KiB, FLASH 0+512KiB. No persistence/update partition is implied.
2. Use exactly one `Peripherals::take`, then `esc_som_board::initialize`. Acquire before actor/service Start. A failed acquire/init does not return reusable hardware; halt safely. Physical outputs after any failure still require electrical evidence. The safe API never arms a motor.
3. Resources are owned values, not borrowed globals. Move LED and UART into sole thread executor services. Preserve them across actor Reset/Stop; never reacquire. GPIO setup is consumed, so services cannot remux any other pads. UART no_std async adapter waits in the service, never in synchronous RTC actions.
4. Construct all storage/tasks/endpoints and freeze all allocator operations. Consume `systick.start(clocks)` and enable CPU interrupts only at this barrier, before the first service/actor polls and external admission. `embassy` exports exactly one SysTick handler. No competing generic time driver or second tick handler. No generic Embassy timer queue features needed.
5. Pin embassy-executor=0.9.1, embassy-time=0.5.1, embassy-time-driver=0.2.2 (`tick-hz-10_000`), critical-section=1.2.0. Target picks cortex-m=0.7.7 `critical-section-single-core`, and executor `arch-cortex-m,executor-thread`; host test supplies critical-section/std only. Do not enable embassy-time/std/mock-driver or a second critical-section implementation in target dependencies. Locks record transitive checksums.
6. Budget at most 16 retained task deadlines, including cancelled/completed tasks whose earlier timer registration has not yet expired. Tasks are statically allocated process-lifetime resources. The table deduplicates by task and keeps earliest deadline; Timer repolls/re-registers if that wake was early. No task reclamation or queue growth. Exhaustion is a fatal bounded fault; do not treat it as a recoverable calibration reject. Non-Embassy wakers are rejected by upstream task_from_waker validation.
7. Read `Instant::now().as_ticks()` in 100us units; `timer::ticks_to_micros` is checked, `micros_to_ticks_ceil` never rounds a deadline earlier. u64 state uses critical sections, not AtomicU64. Time cannot go backward; boot starts at zero and actor reset never resets it.
8. SysTick loses wraps when masked/delayed for >=100us; this driver does not pretend to recover them. Measure total interrupt masking and wake/edge lateness under traffic. No STOP/STANDBY or dynamic clock changes. Timer quantization and executor scheduling add latency; 100us is configured quantum, not measured worst-case latency. LED idle polling contract stays <=1000us; choose earlier physical edge deadlines.
9. UART has no DMA/peripheral IRQ and no application queues here. Async read/write return one byte per success, and flush waits for the admitted byte’s raw EOT through its final stop bit, independent of RX. `is_tx_complete` is the synchronous query. Only one byte may be outstanding; callers must handle would-block even when the TX buffer has space. See [TX completion](uart-completion.md) for bounds and throughput implications. Cancelling/recreating flush preserves completion state in the UART owner and does not cancel transmission. Calls can be bounded with `with_timeout`; dropping a pending read/write has not admitted a byte. `write_all` cancelled after prior successful writes may have transmitted a prefix: owned protocol command/completion service must retain its progress or report truncation. This is normal I/O behavior, not an exactly-once command promise. Error is passed to transport owner for framing/session recovery. 38400 remains a qualification candidate.
10. Full firmware implements allocation-free panic/HardFault/default exception policy; no Drop cleanup is assumed on fault. Sample uses a no-allocation interrupt-disabled halt. BSL reset(false) recovery and clock/UART/LED/timebase measurements belong to the serialized Jetson custodian after artifact review.

No contract ambiguity discovered requiring S0 edits. Remaining constraints are implementation integration and HIL proof obligations, not changes to accepted contracts. Parent/coordinator owns acceptance and dispatch.

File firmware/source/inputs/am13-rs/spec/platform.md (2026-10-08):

# AM13 LED support 0.1

This implements the chip portion of accepted am13-led-target/0.1.0, not a full PAC/HAL. Device take is one-shot per boot and yields disjoint clock, pad/GPIO, UC4 and SysTick owners. Handles remain !Send/!Sync and move into thread executor tasks; only the global time driver shares critical-section-protected RAM with SysTick. No shared MMIO object escapes and no peripheral IRQ accesses GPIO/UART.

Clock selection: factory 32 MHz SYSOSC, USEHSCLK=0, MCLKDIVCFG=7; semi-domain division is bypassed on SYSOSC. UC4 CLKSEL=8, CLKDIV=0, 16x oversampling. Clocks are nominal configuration evidence, never measured frequency. No HSCLK, STOP/STANDBY, PLL or runtime frequency changes. UART config is separate from board-selected pad mux; peripheral enabled only after board mux. Errors precede received data. Each nonblocking call has finite MMIO operations. Async read/write retry using Embassy Timer every 100 us; each successful write returns its admitted prefix (cancellation never hides admitted bytes). Flush waits for tracked TX completion through raw EOT, including the final stop bit, independently of RX. An untouched transmitter is already complete. Admission is limited to one outstanding byte; see [TX completion](uart-completion.md) for races and bounds. This is a foreground adapter, not DMA/IRQ transport throughput qualification.

Driver: embassy-time-driver 0.2.2, embassy-time 0.5.1 at 10000 Hz; embassy-executor 0.9.1. Fixed 16 TaskRef/deadline slots; one earliest outstanding deadline per task, including cancelled timers. It is valid to spuriously wake a cancelled timer's task. Table entry removed before wake, and later timers re-register after an early wake. Driver now is zero before start, increments saturating u64 under critical section, never resets during actor reset. Timestamps use checked ticks*100 for microseconds. Startup consumes the SysTick owner and programs reload 3199; only one handler calls tick. Deadline capacity is a task-count integration budget; overflow latches a fault and halts via fixed panic. No arbitrary waker clone/drop, queue allocation or retry loop. Only Embassy task wakers supported (executor validates them).

Interrupt masking longer than 100 us can lose SysTick events; software cannot reconstruct multiple missed wraps from one pending bit. This is a measured integration constraint, not a wall-clock accuracy guarantee. No IRQ performs application actions. Tick extracts a bounded wake array under CS, then wakes outside it. Runtime allocator/fault-path qualification remains T36/full-image T13.

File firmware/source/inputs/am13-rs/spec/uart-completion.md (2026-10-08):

# UART transmit completion and admission

`is_tx_complete(&mut self)` means all data admitted through this owner has left the transmitter, including the final stop bit. It returns true before the first successful write regardless of reception. Async `flush` uses this query, retrying via the existing 100 us timer. The former `is_tx_idle` API has been removed; downstream callers must use `is_tx_complete`.

Primary authority: TI SPRUJF2B, March 2026/revised August 2026, §29.2.2.5 and §29.5.2.6 (RIS at UART+0x30), §29.5.2.9 (ICLR at +0x48), and §29.5.2.21 (STAT at +0x108). RIS.EOT bit12 asserts only after the last data/flag bit, including STOP, leaves the serializer with no remaining TX buffer data. RIS supports polling regardless of IMASK; writing one to ICLR.EOT clears only that flag. SDK26.01.00.03 `hw_unicommuart.h` agrees. BUSY also covers reception. TXFE describes the buffer, not the serializer, so neither is used as TX completion. Source PDF SHA256: 31aa9d5365f2d892c76b08977001b2653712a1ebf4046c1e9e6d75639f62e53c; SDK header SHA256: 405e22b22548f943c7be3c16b21d7d58685fe61084e61c682d2e9d525fd94384. Local authority paths remain in provenance.json.

The owner keeps one boolean, `tx_pending`, initialized false after peripheral reset/configuration. A successful admission clears stale EOT while no transmission is outstanding, sets the boolean, then writes TXDATA. A pending byte becomes complete only on observed raw EOT. Polling records that completion in the owner without clearing the peripheral flag. The next successful admission clears that old flag before TXDATA. No EOT interrupt is enabled or needed; reset leaves masks disabled. No IIDX read or shared interrupt/DMA owner may consume these indications.

Admission deliberately waits for the previous byte's EOT even if TXFF is clear. At most one byte is outstanding; this forgoes FIFO/serializer pipelining. Allowing another byte while the previous one was shifting would permit an old EOT between clear and TXDATA, falsely completing the new byte. Clearing after TXDATA would instead risk losing a new completion during preemption. Serial admission avoids both races without an interrupt-disabled timing window, guessed transmission delay, or undocumented automatic flag clearing.

Cases and interleavings:

- Before any write, RX-only BUSY and RX errors do not create TX work. Stale EOT is immaterial until cleared before the first admission.
- TXFF rejection happens first and performs no write or state transition. A pending-byte rejection leaves EOT untouched. Under exclusive ownership the buffer cannot become newly full between TXFF read and TXDATA; only this foreground owner can add data.
- If old TX completes before the RIS read, admission can proceed after clearing its EOT. If it completes after a read returning zero, that call returns would-block and a later call observes completion. No byte is silently admitted by a failed call.
- Once old completion is observed, no old TX can finish during the clear-to-write interval. Arbitrarily long preemption before TXDATA is safe. Preemption after TXDATA can let new TX finish immediately; there is no subsequent clear to lose that EOT.
- Repeated completion queries/flush calls remain complete until the next successful admission. Consecutive batches cannot consume a stale flag as their completion.
- Dropping a pending async write admits no byte. Successful writes return one admitted byte immediately without an await after admission. `write_all` may have sent a prefix when cancelled, so the protocol owner must track progress. Dropping/recreating or repolling flush preserves the boolean and raw EOT; it never aborts an admitted transmission.
- RX error clearing masks exclude EOT. EOT clearing masks exclude RX/error flags. Concurrent hardware reception or error indications cannot complete TX and are left for `try_read`. Flush itself does not consume or report RX errors. The exclusive mutable handle still requires the transport service to schedule/drain RX between TX operations; full-duplex throughput/overrun qualification is not implied.

Bounds: `try_write` performs at most two MMIO reads and two MMIO writes, with no loop or critical section. `is_tx_complete` performs at most one read, zero writes; an already complete owner performs none. Fixed RAM cost is one boolean (struct padding/layout may differ); no allocation, dynamic queue, IRQ, or new timer slot beyond existing async waits. Async waits have no inherent wall-clock timeout: stuck hardware stays pending, and owners can apply `with_timeout`. Cancelling a timeout does not authorize peripheral reacquisition/reset. Polling adds the configured timer quantum plus executor/interrupt latency after hardware EOT; the actual bound requires HIL. At one byte per admission, UART saturation and loaded edge/poll latency must be requalified; no line-rate guarantee is made.

Tests use a fixed-storage peripheral model with separate holding/data/stop phases, W1C flags, reception and injected completions at MMIO boundaries. The real Embassy workload covers empty/admitted/cancelled/repoll/repeated-batch paths, RX errors and all-four allocator counters. These are host semantics tests, not native ARM64 execution, measured UART timing or full-image T36 acceptance. The qualified physical diagnostic baseline stays 19200; 38400 remains an unqualified candidate.

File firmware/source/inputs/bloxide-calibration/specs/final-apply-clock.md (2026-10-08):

# Final apply clock binding — T07 F1 correction

This implementation specification binds the existing immutable
`led-calibration-ownership-v0.1.md` deadline/phase policy and
`led-output-slot-binding-v0.1.md` reservation cancellation policy. It does not
revise either contract.

`Owner::apply(request, clock, make_candidate, gate)` accepts a `FnMut() -> u64`
hook instead of a pre-sampled timestamp. The hook is a trusted bounded,
synchronous, infallible, allocation-free read of current monotonic microseconds
in the deadline domain, without wrap during the live service. Sampling a saved
entry timestamp in this hook violates its contract. Borrow platform time from
the owning integration; do not embed runtime/HAL resources in owned messages.
The hook may be passed by mutable reference to avoid destroying owned resources.
Hook/candidate/gate captures must obey the no-heap-after-freeze lifetime rule.

Decision order:

1. Return existing retained/fenced/busy/lifecycle outcomes without running hooks.
2. Sample entry clock; reject expired requests, then check expected revision.
3. Construct and validate the full candidate; validation errors remain retained.
4. For same-value: sample clock again, reject at/after expiry, otherwise retain
   Applied(changed=false) with this sample. No slot, revision or phase change.
5. For changed-value: attempt reservation; retain its existing admission error
   on failure. Once reserved, sample clock again immediately before mutation.
6. At/after expiry, drop the still-unpublished permit and retain Expired without
   active/revision/phase/output changes. Drop must cancel Reserved to Empty.
7. Otherwise commit active/revision, publish infallibly with that final sample
   in CommitRecord, then retain Applied with the identical sample. Component
   publication uses that record timestamp as its new phase epoch.

Exactly two clock reads occur on a validated successful/no-op or final-expiry
path. No clock read occurs after mutation begins. The comparison and commit are
synchronous; this library cannot qualify platform interrupt latency, clock
accuracy, real-time deadlines or runtime slot safety. No new runtime or HAL
abstraction or legacy timestamp API is introduced.

Normative regression: tests/deadlines.rs, covering validation/reservation
advances to deadline 100 and beyond 101, no-op rejection and fresh success,
just-before-expiry 99 publication/phase/outcome, Drop cancellation and retained
results. Existing transaction tests cover release/reset/cancel fencing.

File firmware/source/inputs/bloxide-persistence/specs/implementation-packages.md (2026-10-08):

# Bounded implementation packages after independent design approval

Round-019 independently approved the portable I1-I4 scopes. They are implemented
on this branch and await product review. The package requirements below remain the
reviewed behavior; this status note does not relax them. I5-I7 remain gated and were
not implemented by this dispatch.

| Package / owner | Deliverables and exit |
|---|---|
| I1 T17 portable core | `bloxide-persistence` no_std crate, schema callback interface, checked codec/CRC and recovery classifier. No runtime/HAL/XCP dependency. Implement corrected R1-R3 and erase-integrity-proof.md: complementary body INCLUDING CRC, fixed logical/physical coordinate spaces, Q erase prestate classifier, independent golden vectors/decoder and directed codeword searches C01-C05/C14-C16. Q must not be replaced by an assumption that every Corrupt slot is erasable. No generated Rust edits. |
| I2 T17 service + simulator | Fixed-state command/completion machine, owned buffers, retained results/fences, conservative wear-authority seam. Independent byte/bit/prefix backend with separately written recovery oracle. QualifyErase scans before permit consumption; exercise both Q-safe and Q-unsafe independently invalid media, exact original F1 negative control, erased-marker restoration and repeated interruptions. Finite samples supplement the all-subsets proof. Implement R4-R9 and C06-C13/C17-C20. Core acceptance must not count the production parser as its sole oracle. |
| I3 T17 T07 adapter | Optional adapter crate depending on exact Git calibration c0a693a8811d920d05850cfc2ebcfd7956a2741b, no path override/active checkout. Owner-turn snapshot, fixed one/four-client broker. Public API tests including revision wrap and later RAM edit; no direct active mutation. |
| I4 T17 external reuse | Independent temporary Cargo workspace outside source, consuming this private repository at full immutable commit through Cargo Git, no path dependency. Thermostat schema, 100 save/reboot cycles plus C19 failure sweep. Lock dependencies and capture URL/rev/tree/manifest/Cargo lock hashes. `cargo tree` must show no drone, AM13, GPIO, XCP or runtime dependency for portable core. Do not create another repository without dispatch. |
| I5 T17/Bloxide integration | After reviewed T06 pin, messages are plain owned data, context free synchronous actions, pure TOML blox if an actor is useful, system.toml concrete adapter/backend wiring. Mailbox-free backend owns moved resource; no Reset reacquisition. Generate using pinned source tooling; real-action tests and T36 allocator instrumentation. |
| I6 P protocol owner | Resolve P-OPEN-1/2, review candidate vectors/metadata/error behavior, implement actual endpoint adapter at exact reviewed pins and independent unchanged pyXCP/pya2l tests C21-C23. S0 negative regression mandatory. No upstream client/parser patches or conformance claim. |
| I7 T16/T18 platform integration | T16 qualification of monotone erase/program subset model, coherent ECC/error visibility, slot/granule isolation, Q prestate stability, geometry/regions/RAM execution/timing/budget authority, separate reviewed target artifact release, native runner checks, MCU target builds and serialized UART reset/readback/power-interruption work. No device work from T17 server worker. |

Recommended dependency DAG: I1 -> I2 -> I3 -> I4; I5 requires I3+T06+T36;
I6 requires I3+P wire review and actual reviewed XCP endpoint; I7 requires I2+
T16+runner acceptance and separately authorized hardware procedure. I1-I4 are
useful without I5-I7 but cannot be reported as complete T17 product acceptance.

The F1-r2 design re-review released only I1-I4 portable implementation. No portable
result qualifies AM13 behavior, and no later hardware evidence may substitute for
the required model/physical qualification.

Use Rust1.94.0, CARGO_BUILD_JOBS=2 and a fresh owned /var/tmp NVMe scratch
CARGO_TARGET_DIR; record actual owner/filesystem and preserve final evidence in the
assigned hub. Use normal Cargo cache locks, no lock bypass/retry churn. Required
future commands include cargo test --locked for core+adapter, independent Git
consumer cargo test --locked, cargo check --locked --no-default-features --target
thumbv8m.main-none-eabi, and reviewed-source cargo blox test for integration.
The implementation evidence records the now-executed exact commands separately;
the original design evidence remains design-only.
Host x86_64, MCU thumb and native ARM64 results remain separately labeled.

## Interface handoff summary

Portable: Geometry + Slot IDs + Codec + owned Snapshot -> Save/Resolve/Release/
Quiesce -> owned one-at-a-time backend commands -> exact correlated completions ->
retained Durable/Failed/Indeterminate. Durable view is separately readable.
All values/sizes/fences live in record-and-service-v1.md R1-R9; exact proposed P
wire boundary is profile-p-proposal.md. Next implementation starts with independent
fixtures in tests/test-catalogue.json, not by translating this design checker
into the product simulator. Future readback test must compare canonical bytes,
not just CRC, RAM revision, success status or process exit.

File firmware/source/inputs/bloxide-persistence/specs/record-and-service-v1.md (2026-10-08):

# T17 approved portable persistence contract r2

This contract was approved at design commit 82aa2c5bfbfbeaca67921d41ef087d6e441fb064.
Portable I1–I4 implementation is in this repository; actual correction API details
are in portable-correction-r1.md. It is not an accepted extension to S0. It selects
two disjoint erase units, one record per unit, for payloads of 1..256 bytes. No
journal compaction, migration, arbitrary-address write, flash PGM service or
runtime dependency is in this cut. All logical integers below are unsigned little-endian.
F1 correction: [proof and fault model](erase-integrity-proof.md) is normative for
R1/R2/R3/R7. The filename is retained as a document link, not a format-v1 alias.

## R1 — Inputs and backend guarantees

Construction validates these immutable inputs before external admission. Geometry
and codec registration remain fixed for the provisioning lifetime; changing them
requires separately reviewed migration/reprovisioning, never another boot guess:

| Input | Required contract |
|---|---|
| `E`, `G` | Erase-unit bytes and program granule bytes. G is power of two, 1..256; E is a multiple of G, 512..65536, and E >= M+G. M = round_up(640,G). Other geometry returns UnsupportedGeometry. |
| A, B | Disjoint E-byte regions, each E-aligned, exclusively owned; outside all firmware, boot, security, NONMAIN and other data. Use Slot A/B identifiers in portable commands, never physical addresses. |
| Erased state/transitions | FF bytes. Interrupted erase only raises arbitrary addressed-unit zero bits to one, including stored CRC/marker; no order assumption. Interrupted program only clears a subset of requested bits in the addressed G-byte granule. No overprogram or nonmonotone transitions. Each granule is programmed at most once between erases, including commit. |
| Isolation | An interrupted erase/program can damage only the addressed erase unit/granule respectively; the other slot and already finished granules remain stable. All finished bits remain stable outside the addressed operation; interrupted erase may affect any subset of zero bits within its unit, not merely an ordered prefix. |
| Durable completion | A successful completion means operation finished, voltage/timing requirements met and persistent media state settled. Read returns coherent uncached bytes or explicit read/ECC error; no fabricated FF for unreadable data. |
| Restart | After power cycle the backend establishes that no old write remains active before reads. On logical Reset/timeout it must prove quiescence; resetting a software flag is insufficient. |
| Readback | Backend can read the full slot and distinguish uncorrectable error. Corrections are reported; conservatively quarantine a slot with a corrected error too. |
| Limits | Bounded maximum erase/program/read/quiesce times and watchdog/interrupt policy are required inputs; no unbounded backend polling in an HSM action. |
| Wear authority | Persistently accounted, non-reissued erase permits, per-slot remaining budget, stable quarantine information; see R8. |
| Erase eligibility | Full healthy pre-erase scan must satisfy Q in R3; administrative recovery authorization never waives it. No intervening writer or spontaneous disturbance in the modeled interval. |
| Schema | Nonzero schema ID (u16), exact length <=256, bounded deterministic encode/decode/validate/default callbacks and application policy. Unknown schemas are never guessed. |

These are required guarantees, NOT statements about AM13. T16 must supply exact
MAIN regions, chip revision, G/E/ECC coupling, disturbance scope, allowed repeated
programming, RAM execution/call graph, cache/interrupt access, endurance and timing.
If physical disturbance extends beyond a program granule, G must encompass that
unit and remain within this profile, otherwise reject this backend/profile.
If two independent erase units are unavailable, do not emulate them in one page.
No hardware deployment can proceed without these proofs. The monotone bit model,
including ECC visibility/coupling and voltage-collapse behavior, is UNQUALIFIED
on AM13. An all-cut theorem under these explicit inputs is not a hardware claim.
Arbitrary nonmonotone replacement is distinct residual corruption, not an admitted
modeled interruption that can be silently excluded as a CRC collision.

## R2 — Exact record layout

There are two coordinate spaces. Logical body L is exactly320 bytes (64-byte
header plus256-byte payload area). Physical slot S has E bytes. Encode EVERY
logical byte, including CRC and logical padding: `S[2*i]=L[i]`,
`S[2*i+1]=L[i] XOR FF`, for i=0..319. Complement test is bitwise XOR=FF for each
adjacent byte pair. Each bit pair is01 or10, never00 or11. No raw field can bypass
this check. Decode L only after all320 pairs pass. Physical code body is640 bytes;
M=round_up(640,G), programmed span M+G <=1024, separate one-shot commit granule.

| Logical offset | Logical bytes | Meaning / validity |
|---|---:|---|
| 0 | 8 | Magic hex `42 4c 58 50 45 52 53 32` (BLXPERS2) |
| 8 | 2 | Record format = 2 |
| 10 | 2 | Application schema ID, nonzero |
| 12 | 4 | Payload length 1..256; must equal registered schema length |
| 16 | 8 | Persistent record sequence 1..2^64-1 |
| 24 | 8 | Captured RAM owner's service_epoch |
| 32 | 4 | Captured RAM owner's ActiveRevision.get() |
| 36 | 4 | Persistence request session_generation |
| 40 | 8 | Persistence request sequence (operation identity, not record sequence) |
| 48 | 12 | Reserved, exactly zero |
| 60 | 4 | CRC-32C, encoded just like every other byte |
| 64 | length | Canonical schema payload bytes; no struct padding/pointers |
| 64+length | 320-(64+length) | Logical padding exactly FF (physical pairs FF,00) |

| Physical offset | Bytes | Meaning / validity |
|---|---:|---|
| 0 | 640 | Encoded logical L; logical range [a,b) occupies physical [2a,2b) |
| 640 | M-640 | Alignment padding exactly FF, outside logical CRC |
| M | G | Commit marker: every byte exactly00 |
| M+G | E-(M+G) | Unused tail exactlyFF |

For G1,2,4,8,16,32,64,128, M=640; G256 has M=768. Minimum
legal E is `round_up(max(512,M+G),G)`: 641,642,644,648,656,672,
704,768,1024 respectively. E512 is now unsupported for every G; that is a
portable layout cost, not a claim that a particular device offers larger sectors.
Total flash reservation is2E. All bounds are checked before indexing/commands.

CRC-32C/Castagnoli parameters remain polynomial0x1EDC6F41, reflected0x82F63B78,
init/xoroutFFFFFFFF, refin/refout true; ASCII123456789 -> E3069283. Feed decoded
logical L[0,60), then L[64,320), ascending order. Exclude L[60,64); physical
alignment/marker/tail are outside CRC and checked exactly. CRC no longer depends
on G. It remains a corruption detector, not the erase-integrity mechanism.
The complementary encoding covers stored CRC too: simultaneous data/CRC erase
changes cannot map between distinct accepted bodies. No CRC-collision exception
is needed for the modeled interruption theorem.

This replaces the rejected, never-implemented raw BLXPERS1 proposal. Raw v1 is
not a legacy alias, not parsed as an alternate layout and not migrated on boot.
The fixed encoded BLXPERS2 envelope is the only candidate format here.

LED example schema ID 1: length 4; period u16 milliseconds then duty u16 permille;
validate 100..10000 and 0..1000, defaults (1000,500). This schema belongs to the
consumer, not portable library constants. Unrelated thermostat fixture schema ID
2: length 8; signed little-endian i32 setpoint_mC 5000..35000, u32 hysteresis_mC
100..5000, additionally setpoint-hysteresis >= 0; defaults (20000,1000). Portable
core only sees registered schema codec and bytes. Neither fixture is firmware.

## R3 — Validity and recovery precedence

Scan both full slots into bounded scratch storage after qualified idle; read/ECC
error is Unreadable (including an error accompanying FF bytes). A healthy all-FF
slot is Empty. Inexact commit marker is Uncommitted. With exact-zero marker, any
noncomplementary body pair is Corrupt; do not inspect untrusted version/sequence
first. Decode the fixed320-byte body, then verify magic, nonzero schema/sequence,
length1..256, reserved zeros, logical padding, physical alignment/tail and CRC.
Any failure is Corrupt. This defines envelope validity independently of supported
format/schema. Only then may unsupported format/schema classify Unsupported.
For supported format2 and registered schema, require its exact length and full
semantic decode/validation to classify Valid. Format0 is unsupported if its
common envelope is valid; schema0 or sequence0 is always malformed. Never invoke
an unknown decoder or substitute that schema's defaults.

BLXPERS2 declares this exact fixed logical/physical common envelope and CRC domain
across future format values. A future incompatible encoding/geometry needs new
magic plus separately reviewed migration, never a heuristic alternate decoder.
Every accepted field, including version/schema and stored CRC, lies within the
complementary body. Partial erase cannot manufacture an Unsupported record or a
duplicate-sequence ambiguity from a valid predecessor; see R7.

| Slot classifications | Boot result |
|---|---|
| Any Unsupported | Explicit Defaults(UnsupportedVersion), reads/diagnostics only; no erase/save until separately reviewed migration/reprovisioning. Even a lower-sequence unknown record triggers this policy. |
| Two Valid, distinct sequence | Choose greater numeric sequence; no modular comparison. |
| Two Valid, equal sequence, identical bytes [0,M+G) | Choose A deterministically, report Duplicate; both represent the same configuration. |
| Two Valid, equal sequence, different bytes | Defaults(Ambiguous), lock writes; never guess newer by address or CRC. |
| One Valid | Load it; report other slot's classification. Backend recovery/quarantine must authorize reuse of the other slot and Q below must pass before erase. |
| Neither Valid | Defaults(reason bitset Empty/Uncommitted/Corrupt/Unreadable); keep explicit diagnosis. Only two Empty, healthy slots are automatically writable. Otherwise require backend recovery authorization AND Q before erasing either. With no selected Valid record, an authorized defaults-start uses sequence1 and the same defaults/new oracle; never trust corrupt sequence bytes. |

Before EVERY erase, perform a complete healthy read of the inactive target in
QualifyErase. Qualified stable reads and exclusive ownership hold until command
completion/reconciliation. The structural erase-eligibility predicate Q accepts:

- Q1: any marker bit is1; OR
- Q2: any bit position in a body byte pair has both bits1 (`d & complement !=0`);
  OR
- Q3: every body pair is complementary, marker is zero, physical alignment/tail
  are FF, and normal classification is Corrupt or a subordinate Valid record
  (lower sequence than selected current, or exact duplicate of it).

Unsupported/ambiguous recovery, read/ECC error, selected-slot discrepancy or
unreconciled backend quarantine denies writes regardless of Q. A Valid target
with no selected current is a recovery discrepancy, not an erasable default.
If none of Q1-Q3 holds, retain Failed(NoNewCommit, UnsafeErasePrestate), lock writes,
consume no erase permit and require separately reviewed reprovisioning. No partial
program, invalidation-marker trick or administrative authorization may bypass Q.
QualifyErase can stream: retain any-marker-one, any-pair11, all-pairs-complementary,
exact padding/tail flags and bounded decoded body. G1 reads may bridge pairs using
one carry byte. Fixed memory only. See the proof's00-pair and damaged-tail negative
controls; unconditional erasure of arbitrary invalid records is unsafe.
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

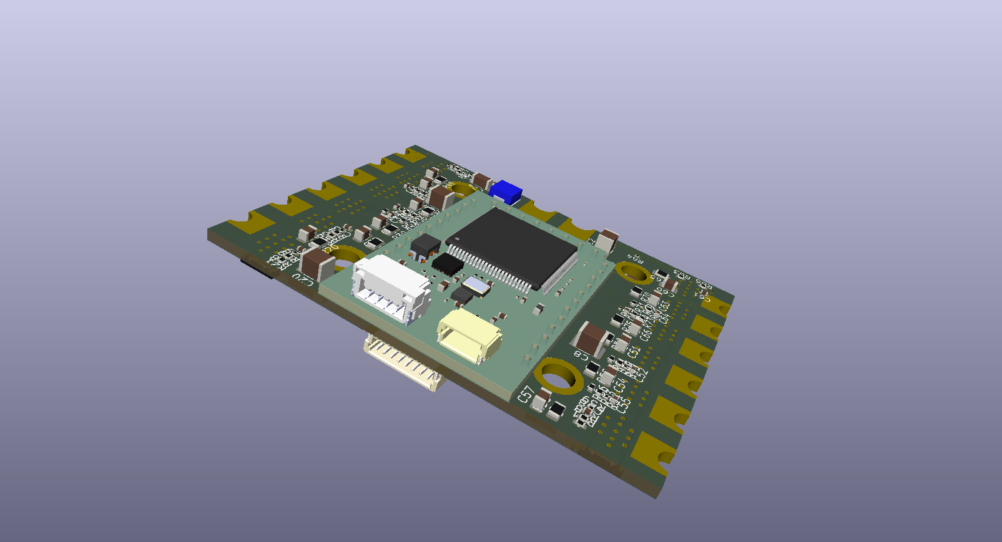
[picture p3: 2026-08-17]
mainboard/mainboard_bottom.png

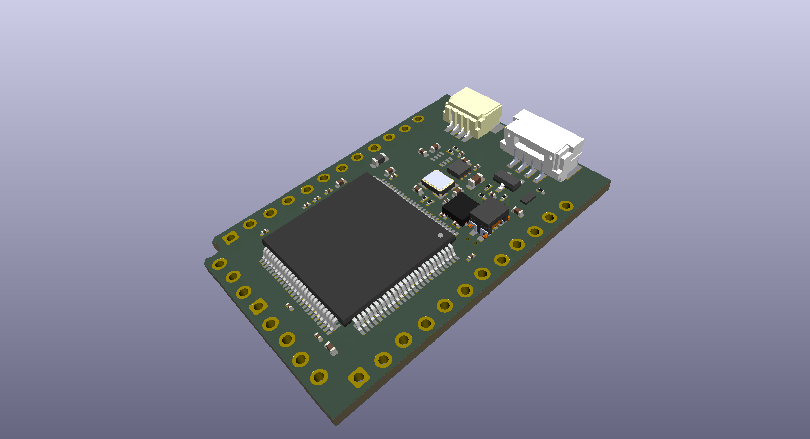
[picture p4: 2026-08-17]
som/som_top.png

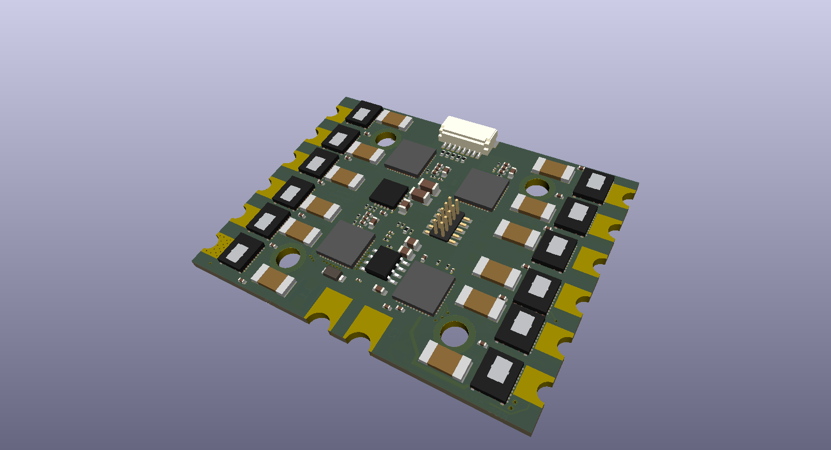
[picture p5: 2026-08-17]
mainboard/mainboard_top.png

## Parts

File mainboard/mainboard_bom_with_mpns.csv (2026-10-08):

Reference | Qty | Value | MPN | Cap Dielectric | Cap Voltage Rating | DNP | Footprint | Datasheet
C1 | 1 | 1000uF | TBD | Aluminum electrolytic | 35v | DNP
C2,C8,C14,C20 | 4 | 10uF | C1210C106K5RACTU | X7R | 50V |  | Capacitor_SMD:C_1210_3225Metric
C3,C9,C15,C21,C27,C78,C84 | 7 | .1uF | CC0201KRX7R6BB104 | X7R | 10V |  | Capacitor_SMD:C_0201_0603Metric
C4,C10,C16,C22,C26,C82,C85 | 7 | 1uF | CC0402KRX7R6BB105 | X7R | 10V |  | Capacitor_SMD:C_0402_1005Metric
C5,C11,C17,C23 | 4 | .1uF | CC0402KRX7R9BB104 | X7R | 50V |  | Capacitor_SMD:C_0402_1005Metric
C6,C12,C18,C24 | 4 | 1uF | C0603C105K3RACTU | X7R | 25V |  | Capacitor_SMD:C_0603_1608Metric
C7,C13,C19,C25 | 4 | 47nF | CC0402KRX7R9BB473 | X7R | 50V |  | Capacitor_SMD:C_0402_1005Metric
C28,C32,C36,C40,C44,C48,C52,C56,C60,C64,C68,C72 | 12 | 1nF | GRM0335C1H102JE01D | C0G/NP0 | 50V |  | Capacitor_SMD:C_0201_0603Metric
C29,C33,C37,C41,C45,C49,C53,C57,C61,C65,C69,C73 | 12 | 2.2uF | C2012X7R1H225K125AC | X7R | 50V |  | Capacitor_SMD:C_0805_2012Metric
C30,C34,C38,C42,C46,C50,C54,C58,C62,C66,C70,C74 | 12 | 4.7nF | CC0402KRX7R0BB472 | X7R | 100V |  | Capacitor_SMD:C_0402_1005Metric
C31,C35,C39,C43,C47,C51,C55,C59,C63,C67,C71,C75 | 12 | 10nF | CC0402KRX7R0BB103 | X7R | 100V |  | Capacitor_SMD:C_0402_1005Metric
C76,C77 | 2 | 4.7uF | C2012X7R1H475K125AC | X7R | 50V |  | Capacitor_SMD:C_0805_2012Metric
C79 | 1 | 6.8nF | CC0201KRX7R7BB682 | X7R | 16V |  | Capacitor_SMD:C_0201_0603Metric
C80 | 1 | 39pF | CC0201JRNPO9BN390 | C0G (NP0) | 50V |  | Capacitor_SMD:C_0201_0603Metric
C81,C86,C87, C88 | 4 | 22uF | CC1206MKX7R7BB226 | X7R | 16V |  | Capacitor_SMD:C_1206_3216Metric
C83 | 1 | 10uF | C2012X7R1A106K125AC | X7R | 10V |  | Capacitor_SMD:C_0805_2012Metric
D1 | 1 | D | SMAJ26A |  |  |  | SMAJ26A:SMAJ26A
D2 | 1 | LED | APHHS1005LZGCK-V |  |  |  | LED_SMD:LED_0402_1005Metric | https://www.kingbrightusa.com/product.asp?catalog_name=LED&product_id=APHHS1005LZGCK-V
D3 | 1 | D | PMEG6030AEXE-QX |  |  |  | PMEG6030AEXE-QX:PMEG4030AEXEQX
J1 | 1 |  | N/A - PCB wire pad |  |  |  | WirePad_Battery_2P_5.0x9.0_DualSide:WirePad_Battery_2P_5.0x9.0_DualSide
J2,J3,J4,J5 | 4 |  | N/A - PCB wire pad |  |  |  | WirePad_Motor_3P_4.0x6.0_DualSide:WirePad_Motor_3P_4.0x6.0_DualSide
J6 | 1 | Conn_01x08_Pin | SM08B-SRSS-TB(LF)(SN) |  |  |  | SM08B_SRSS_TB_new:JST_SM08B-SRSS-TB
J7 | 1 | ARM/JTAG | DNP |  |  | DNP
J8 | 1 | MikroBUS L | DNP |  |  | DNP
J10 | 1 | MikroBUS R | DNP |  |  | DNP
L1 | 1 | 10uH | SRP4020T-100M |  |  |  | SRP4020T-100M:INDPM4441X200N
R1,R3,R4,R6,R7,R8,R10,R12,R20,R22. R2,R5,R9,R11 | 14 | 10k | RC0201FR-0710KL |  |  |  | Resistor_SMD:R_0201_0603Metric
R13,R14,R15,R16,R17 | 5 | 0 | RC0402JR-070RL |  |  |  | Resistor_SMD:R_0402_1005Metric
R18,R23 | 2 | 2.2k | RC0201FR-072K2L |  |  |  | Resistor_SMD:R_0201_0603Metric
R19 | 1 | 100k | RC0402FR-07100KL |  |  |  | Resistor_SMD:R_0402_1005Metric
R21 | 1 | 4.7k | RC0201FR-074K7L |  |  |  | Resistor_SMD:R_0201_0603Metric
R24,R29,R34,R39,R44,R49,R54,R59,R64,R69,R74,R79 | 12 | 33k | RC0402FR-0733KL |  |  |  | Resistor_SMD:R_0402_1005Metric
R25,R30,R35,R40,R45,R50,R55,R60,R65,R70,R75,R80 | 12 | 3.3k | RC0201FR-073K3L |  |  |  | Resistor_SMD:R_0201_0603Metric
R26,R31,R36,R41,R46,R51,R56,R61,R66,R71,R76,R81 | 12 | 2.21 | CRCW08052R21FKEAHP |  |  |  | Resistor_SMD:R_0805_2012Metric
R27,R32,R37,R42,R47,R52,R57,R62,R67,R72,R77,R82 | 12 | 4.7 | RC0402FR-074R7L |  |  |  | Resistor_SMD:R_0402_1005Metric
R28,R33,R38,R43,R48,R53,R58,R63,R68,R73,R78,R83 | 12 | 1mOhm | CSS2H-2512R-1L00F |  |  |  | CSS2H-2512R-1L00F_new:RES_1L00x_BRN
R84 | 1 | 162k | RC0201FR-07162KL |  |  |  | Resistor_SMD:R_0201_0603Metric
R85 | 1 | 10.5k | RC0201FR-0710K5L |  |  |  | Resistor_SMD:R_0201_0603Metric
R86 | 1 | 2k | RC0201FR-072KL |  |  |  | Resistor_SMD:R_0201_0603Metric
R87 | 1 | 13k | RC0201FR-0713KL |  |  |  | Resistor_SMD:R_0201_0603Metric
R88,R89,R90 | 3 | 0 | RC0201JR-070RL |  |  |  | Resistor_SMD:R_0201_0603Metric
TH1,TH2,TH3,TH4 | 4 | Thermistor_NTC | NCU15XH103F60RC |  |  |  | Resistor_SMD:R_0402_1005Metric
U1,U2,U3,U4 | 4 | DRV8323RSRGZT | DRV8323RSRGZT |  |  |  | DRV8323RSRGZT_new:RGZ0048A | https://www.ti.com/lit/gpn/drv8323r
U5,U6,U7,U8,U9,U10,U11,U12,U13,U14,U15,U16 | 12 | CSD88599Q5DC | CSD88599Q5DC |  |  |  | CSD88599Q5DC:DMM0022A | https://www.ti.com/lit/gpn/csd88599q5dc
U17 | 1 | TPS54360BDDAR | TPS54360BDDAR |  |  |  | TPS54360BDDAR_new:U_DDA_TEX | https://www.ti.com/lit/gpn/tps54360b
U18 | 1 | TPS7A4701RGWR | TPS7A4701RGWR |  |  |  | TPS7A4701RGWR_new:RGW0020A-MFG | https://www.ti.com/lit/gpn/tps7a47

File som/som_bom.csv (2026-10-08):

Reference | Qty | Value | DNP | Footprint | Datasheet | Manufacturer | MPN | Dielectric | Voltage Rating | Recommended Footprint | Review Notes | MPN Source
C1,C14 | 2 | 10uF |  | Capacitor_SMD:C_0603_1608Metric |  | Murata | GRM188Z71A106KA73D | X7R | 10 VDC | Capacitor_SMD:C_0603_1608Metric | 10uF bulk on 3.3V/5V rails. X7R, 10V. Verify effective capacitance under DC bias if regulator stability depends on the full nominal value. | https://www.murata.com/en-global/products/productdetail?partno=GRM188Z71A106KA73D
C2,C10 | 2 | 2.2uF |  | Capacitor_SMD:C_0402_1005Metric |  | Murata | GRM155Z71A225KE44D | X7R | 10 VDC | Capacitor_SMD:C_0402_1005Metric | 2.2uF bulk for VDDA/VREF. Current 0402 footprint can stay; selected part is X7R. | https://www.murata.com/en-global/products/productdetail?partno=GRM155Z71A225KE44D
C3,C4,C5,C6,C7,C8,C9,C11,C15,C16,C19,C20, C23 | 13 | .1uF |  | Capacitor_SMD:C_0201_0603Metric |  | Murata | GRM033Z71C104KE14D | X7R | 16 VDC | Capacitor_SMD:C_0201_0603Metric | 0.1uF decoupling. Genuine 0201 X7R is available, so these can remain 0201. | https://www.murata.com/en-global/products/productdetail?partno=GRM033Z71C104KE14D
C12,C13 | 2 | 18pF |  | Capacitor_SMD:C_0402_1005Metric |  | Murata | GRM1555C1H180JA01D | C0G / NP0 | 50 VDC | Capacitor_SMD:C_0402_1005Metric | Crystal load capacitors. Use C0G/NP0 for low temperature coefficient and negligible voltage coefficient. | https://www.murata.com/en-global/products/productdetail?partno=GRM1555C1H180JA01D
C17 | 1 | 4.7nF |  | Capacitor_SMD:C_0201_0603Metric |  | YAGEO | CC0201KRX7R9BB472 | X7R | 50 VDC | Capacitor_SMD:C_0201_0603Metric | CAN split-termination center capacitor. X7R is appropriate; 50V rating permits the existing 0201 footprint. | https://yageogroup.com/content/datasheet/asset/file/UPY-GPHC_X7R_6_3V-TO-250V
C18 | 1 | 1uF |  | Capacitor_SMD:C_0402_1005Metric |  | Murata | GRM155Z71A105KE01D | X7R | 10 VDC | Capacitor_SMD:C_0402_1005Metric | 1uF on 3.3V debug input. Current 0402 footprint can stay. | https://www.murata.com/en-global/products/productdetail?partno=GRM155Z71A105KE01D
C21,C22 | 2 | 4.7uF |  | Capacitor_SMD:C_0402_1005Metric |  | Murata | GRM188Z71A475KE15D | X7R | 10 VDC | Capacitor_SMD:C_0603_1608Metric | CHANGE schematic footprint from 0402 to 0603 to meet the strict X7R-only requirement at 4.7uF/10V. | https://www.murata.com/en-global/products/productdetail?partno=GRM188Z71A475KE15D
CR1 | 1 | ESD2CAN24DBZRQ1 |  | ESD2CAN24DBZRQ1:SOT-23_DBZ_TEX | ESD2CAN24DBZRQ1 | Texas Instruments | ESD2CAN24DBZRQ1 |  |  | ESD2CAN24DBZRQ1:SOT-23_DBZ_TEX |  | https://www.ti.com/product/ESD2CAN24-Q1
D1 | 1 | LED |  | LED_SMD:LED_0402_1005Metric |  | Kingbright | APHHS1005LZGCK-V |  |  | LED_SMD:LED_0402_1005Metric | Green 525nm low-current 0402 status LED. Typical Vf 2.65V at 2mA; with R8 = 2.2kΩ from 3.3V, nominal LED current is about 0.30mA. | https://www.kingbrightusa.com/product.asp?catalog_name=LED&product_id=APHHS1005LZGCK-V
FB1 | 1 | FerriteBead |  | Inductor_SMD:L_0603_1608Metric |  | Murata | BLM18EG121SN1D |  |  | Inductor_SMD:L_0603_1608Metric | 120 ohm @ 100MHz, 2A-rated ferrite bead for VDD-to-VDDA filtering. | https://www.murata.com/en-global/products/productdetail?partno=BLM18EG121SN1D
J1 | 1 | Qwiic |  | SM04B-SRSS-TB_new:CONN_SM04B-SRSS-TB_JST |  | JST | SM04B-SRSS-TB |  |  | SM04B-SRSS-TB_new:CONN_SM04B-SRSS-TB_JST | JST notes that (LF)(SN) is displayed on the label. | https://www.jst-mfg.com/product/index.php?search_product=SM04B-SRSS-TB&type=1
J2 | 1 | Drone_CAN |  | SM04B_GHS_TB_new:JST_SM04B-GHS-TB |  | JST | SM04B-GHS-TB |  |  | SM04B_GHS_TB_new:JST_SM04B-GHS-TB | JST notes that (LF)(SN) is displayed on the label. | https://www.jst-mfg.com/product/index.php?search_product=SM04B-GHS-TB&type=1&lang=2
J3 | 1 | ZEPTO_DEBUG | DNP | Connector_PinHeader_2.54mm:PinHeader_1x08_P2.54mm_Vertical |  | DNP | DNP - no procurement |  |  | Connector_PinHeader_2.54mm:PinHeader_1x08_P2.54mm_Vertical | Debug header is marked DNP.
J5 | 1 | MikroBUS L | DNP |  |  | DNP | DNP - no physical footprint |  |  |  | MikroBUS L is marked DNP and has no physical footprint.
J6 | 1 | MikroBUS R | DNP |  |  | DNP | DNP - no physical footprint |  |  |  | MikroBUS R is marked DNP and has no physical footprint.
L1 | 1 | ACT1210-101-2P-TL00 |  | ACT1210-101:IND_01-2P-TL00_TDK | ACT1210-101-2P-TL00 | TDK | ACT1210-101-2P-TL00 |  |  | ACT1210-101:IND_01-2P-TL00_TDK |  | https://product.tdk.com/en/search/emc/emc/cmf_cmc/info?part_no=ACT1210-101-2P-TL00
R1,R5,R14,R15 | 4 | 0 | DNP | Resistor_SMD:R_0201_0603Metric |  | YAGEO | RC0201JR-070RL |  |  | Resistor_SMD:R_0201_0603Metric | DNP option links; MPN provided for the populated option if ever stuffed. | https://www.yageo.com/en/ProductSearch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
R2,R6,R10 | 3 | 10k |  | Resistor_SMD:R_0201_0603Metric |  | YAGEO | RC0201FR-0710KL |  |  | Resistor_SMD:R_0201_0603Metric |  | https://www.yageo.com/en/ProductSearch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
R3,R4,R7,R13,R17,R18 | 6 | 0 |  | Resistor_SMD:R_0201_0603Metric |  | YAGEO | RC0201JR-070RL |  |  | Resistor_SMD:R_0201_0603Metric |  | https://www.yageo.com/en/ProductSearch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
R8 | 1 | 2.2k |  | Resistor_SMD:R_0201_0603Metric |  | YAGEO | RC0201FR-072K2L |  |  | Resistor_SMD:R_0201_0603Metric |  | https://www.yageo.com/en/ProductSearch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
R9 | 1 | 1.5k |  | Resistor_SMD:R_0201_0603Metric |  | YAGEO | RC0201FR-071K5L |  |  | Resistor_SMD:R_0201_0603Metric |  | https://www.yageo.com/en/ProductSearch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
R11,R12 | 2 | 4.7k |  | Resistor_SMD:R_0201_0603Metric |  | YAGEO | RC0201FR-074K7L |  |  | Resistor_SMD:R_0201_0603Metric |  | https://www.yageo.com/en/ProductSearch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
R16,R19 | 2 | 60.4 |  | Resistor_SMD:R_0201_0603Metric |  | YAGEO | RC0201FR-0760R4L |  |  | Resistor_SMD:R_0201_0603Metric | 1% split CAN termination resistors. | https://www.yageo.com/en/ProductSearch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
R20 | 1 | 499 |  | Resistor_SMD:R_0201_0603Metric |  | YAGEO | RC0201FR-07499RL |  |  | Resistor_SMD:R_0201_0603Metric |  | https://www.yageo.com/en/ProductSearch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
R21 | 1 | 180k |  | Resistor_SMD:R_0201_0603Metric |  | YAGEO | RC0201FR-07180KL |  |  | Resistor_SMD:R_0201_0603Metric |  | https://www.yageo.com/en/ProductSearch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
R22 | 1 | 100k |  | Resistor_SMD:R_0201_0603Metric |  | YAGEO | RC0201FR-07100KL |  |  | Resistor_SMD:R_0201_0603Metric |  | https://www.yageo.com/en/ProductSearch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
U1 | 1 | XAM13E23019GTPZ |  | XAM13E23019GTPZ_new:PZ0100A-MFG | https://www.ti.com/lit/gpn/am13e23019 | Texas Instruments | XAM13E23019GTPZ |  |  | XAM13E23019GTPZ_new:PZ0100A-MFG | Verify the intended production-qualified/orderable AM13 part before volume release. | https://www.ti.com/product/AM13E23019/part-details/XAM13E23019GTPZ
U2 | 1 | TCAN844DRBRQ1 |  | TCAN844DRBRQ1:DRB0008J-MFG | https://www.ti.com/lit/gpn/tcan844-q1 | Texas Instruments | TCAN844DRBRQ1 |  |  | TCAN844DRBRQ1:DRB0008J-MFG |  | https://www.ti.com/product/TCAN844-Q1
U3 | 1 | TPS2116DRLR |  | TPS2116DRLR_new:DRL0008A-MFG | https://www.ti.com/lit/gpn/tps2116 | Texas Instruments | TPS2116DRLR |  |  | TPS2116DRLR_new:DRL0008A-MFG |  | https://www.ti.com/product/TPS2116
U4 | 1 | TPS22950YBHR |  | TPS22950YBHR_new:IC_TPS22950YBHR |  | Texas Instruments | TPS22950YBHR |  |  | TPS22950YBHR_new:IC_TPS22950YBHR |  | https://www.ti.com/product/TPS22950
U5 | 1 | TPS7A2633DRVR |  | TPS7A2633DRVR_new:DRV0006A | https://www.ti.com/lit/gpn/tps7a26 | Texas Instruments | TPS7A2633DRVR |  |  | TPS7A2633DRVR_new:DRV0006A |  | https://www.ti.com/product/TPS7A26
Y1 | 1 | ECS-250-12-33-AGN-TR |  | ECS_250_12_33_AGN_TR:XTAL_ECS-250-12-33-AGN-TR |  | ECS Inc. | ECS-250-12-33-AGN-TR |  |  | ECS_250_12_33_AGN_TR:XTAL_ECS-250-12-33-AGN-TR | 25MHz crystal; C12/C13 are specified as C0G/NP0 load capacitors. | https://ecsxtal.com/store/product/ecs-250-12-33-agn-tr/

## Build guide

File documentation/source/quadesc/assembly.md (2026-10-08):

(mechanical-assembly)=
# Mounting and cooling

The QuadESC PCB is **60 × 48 mm**. Allow room on both sides for components, the installed SoM, connectors and wiring. The PCB outline alone is not the full assembly envelope.

## Fit the board into your system

Use the [board views](overview.md#board-views) to plan access to battery terminals J1, motor terminals J2–J5, FC connector J6 and debug header J7. Leave access to the installed SoM's reset and BSL connections for programming and recovery.

Keep conductive mounts and enclosure surfaces clear of exposed pads and components. Support the battery and motor wires so movement does not pull on their solder joints. Leave clearance for the underside components and module rather than resting the board directly on a flat conductive surface.

## Plan for cooling

Leave airflow around the four power stages and allow heat to escape from the enclosure. Board temperature depends on current, airflow, ambient temperature and load duration; use the [temperature scale](sensing.md#board-temperature-from-the-thermistors) to monitor each stage while developing your application.

The [electrical targets](characterization.md#electrical-targets) describe the intended operating range. Establish the usable current for your mounting and cooling arrangement before sustained motor operation.

## Access for service

Disconnect battery power before servicing wiring or the board. Keep programming connections accessible after installation so an application can be replaced through BSL or SWD. See [care and service](maintenance.md) for workbench checks after a repair.

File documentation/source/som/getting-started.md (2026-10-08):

# Getting started

The AM13E SoM ships with **TI's ROM bootloader (BSL) only**. Load your application before using its sensing, communications or timed outputs. The module can serve a custom carrier or a standalone development setup.

## Power and connections

1. Find J2 using the [connector locator](identity.md) and [pad table](connectors.md). Check pin 1 from the board view before making a cable.
2. Supply 3.3 V digital debug power at J2.1, or use regulated carrier power at the `+VDC` pads as described in [power](power.md). Check the probe's power direction before connecting it.
3. Choose a programming interface. For SWD, connect J2.2 SWDIO, J2.3 SWCLK, J2.7 reset and J2.5 ground, plus the probe's required supply/reference connection. For ROM UART, connect module TX at J2.4 to host RX and module RX at J2.6 to host TX, with ground at J2.5 and compatible logic levels.
4. To invoke BSL, hold J2.8 (`BSL_INVOKE`, PA6) high during reset or power-on. Use a host programmer that supports this MCU's TI BSL protocol. An ASCII serial terminal is not a BSL programmer.
5. Program and verify your application's image at its linked address. Release BOOT low and reset to run it. Follow [programming an application](firmware.md) for image-layout and debug checks.

Debug power runs the digital circuitry. ADC acquisition also needs VAA, and the CAN transceiver needs its 5 V supply. The [power diagram](power.md) shows these separate paths. [Boot and recovery](boot.md) gives the ROM CAN settings and recovery connections.

## Check your application's first output

Choose an observable startup action in your application, such as a debug breakpoint or UART message. For UART, configure UC4 on PA0/PA1 and use matching host settings. The [interface guide](interfaces.md) lists the mux values. If startup is silent, check the linked image address, boot selection and UART configuration using [debugging and peripheral checks](diagnostics.md).

## Explore the interfaces

Choose ADC, PWM, I²C, SPI or CAN resources using the [interface cheat sheet](interfaces.md). The [analog guide](analog.md) explains acquisition and conversion; [timed outputs](timing.md) covers shared timers, output pairs and capture.

For a custom carrier, start with [carrier design](carrier.md), which brings together power, shared pins, external devices and programming access.

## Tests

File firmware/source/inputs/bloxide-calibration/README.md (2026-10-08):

# bloxide-calibration

Portable, allocation-free calibration descriptors, validated scalar values,
stable virtual maps, and owner-mediated mutation contracts.

The runtime crate is `no_std` and has no Bloxide runtime, XCP, hardware, drone,
or measurement dependency. It implements the generic ownership defined by the
immutable S0 contracts; component repositories retain their own complete-value
and cross-field policy. The optional `std` feature provides owned deterministic
JSON exchange structures for host tools. Firmware uses checked compile-time
descriptors and does not parse JSON.

## Main contracts

- `BoundedU16`, `BoundedU32`, `BoundedI32`, and `define_bounded_f32!` create
  unit-aware values with private representations and checked byte decoding.
- `VariableDescriptor` and `Registry` reject invalid defaults/types/policies,
  duplicate identities, overlapping/overflowing regions, gaps, cross-region
  access, read-only writes, and incomplete scalar writes.
- `Owner` serializes one global mutation, retains terminal results, fences
  retired request sequences, represents cancel-before-apply tombstones, and
  preserves active state/outcomes during coordinated reset reconciliation.
- `CommitGate` requires bounded admission before changed state is committed.
  Its publication step is infallible; physical completion/fault status is a
  separate concern and cannot rewrite `Applied` as a rejection. Same-value
  assignments do not reserve output, increment revision, or restart effects.
- `Owner::apply(request, clock, make_candidate, gate)` takes a bounded,
  infallible `FnMut() -> u64` monotonic microsecond hook. Read the live clock
  inside the hook, in the deadline's time domain. The owner samples again after
  validation for a no-op or after reservation immediately before mutation.
  At/after expiry it cancels the unpublished permit and retains `Expired`;
  success uses the final sample in both the record and outcome. Component
  publication uses that record time for its phase epoch. Hook/gate/capture
  cleanup must obey the startup-only heap rule; borrow persistent resources.

The local API binding and regression map are in
[`specs/final-apply-clock.md`](specs/final-apply-clock.md).

## Scope boundaries

LED phase calculation/output-slot synchronization belongs in `bloxide-led`.
XCP address-to-wire behavior and A2L export belong in `bloxide-xcp`.
Read-only coherent snapshots and bounded acquisition storage belong in
`bloxide-measurement`. Persistence and physical I/O are separate capabilities.

Contract source: `contracts-s0-v0.1.1`, archive SHA-256
`f6f75d443d96dd762d3640e1acc76480243eabc88fd441574b4cad4f4f6705db`.
No full ASAM conformity or hardware validation is claimed.

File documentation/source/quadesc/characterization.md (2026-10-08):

# Specifications and compatibility

QuadESC combines a four-channel power stage with a reusable controller module. The values below describe the power-stage design targets and help explain the intended battery range and cooling needs.

## Electrical targets

| Parameter | Design target |
|---|---|
| Battery | 3S–6S, 9–25.2 V |
| Design maximum | 32 V |
| Continuous current per motor | 40 A |
| Burst current per motor | 70 A |

**The current targets are not established operating ratings.** Allowable current depends on cooling, ambient temperature and load duration. No burst duration is specified for the 70 A target, and the 32 V design maximum is not a recommended supply setting. Plan operation around the battery range and the thermal behavior of the complete assembly.

## Firmware compatibility

Factory ROM provides TI BSL. Use the <a href="../som/firmware.html">SoM programming guide</a> to load your application. Motor operation needs code that sequences the gate drivers, acquires feedback at the right time and handles faults.

For flight-controller use, the command decoder and telemetry format need to match the connected controller. The DSHOT labels identify signal routes; the application must configure capture and decoding to receive commands. See [FC integration](integration.md) and [shared control resources](control.md) for the hardware relationships.

## Measurement limits

Current and voltage conversions depend on reference voltage, component values and the gate driver's current-sense gain. The formulas in [sensing](sensing.md) use nominal values. Check the actual reference and gain when comparing a reading with an instrument.

The [temperature scale](sensing.md#board-temperature-from-the-thermistors) gives a nominal ADC-to-Celsius estimate for all four channels. Confirm the fitted thermistor's curve before using that estimate for thermal control. The sensors measure nearby board temperature. Low-side current samples also depend on switching state, so their timing matters as much as their scale.

## Understanding thermal behavior

Board copper, airflow and the duration of a load all affect temperature. A short pulse and a sustained load at the same current produce different heating; repeated pulses can accumulate heat. Compare channels under similar supply and cooling conditions, and watch temperatures as load increases.

Startup, reset and fault handling affect the gate waveforms as well as steady operation. Check those transitions when evaluating a motor-control application. The [power chapter](power.md) explains why shunt heating rises quickly with current.

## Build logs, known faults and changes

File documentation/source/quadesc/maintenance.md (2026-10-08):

# Care and service

Disconnect the supply and loads before working on the board. Begin with the connections and parts near the symptom, then check the affected circuit before returning to motor operation.

## Service checks

Inspect repaired joints and check continuity while unpowered. Next, power the logic and check the supply rails and analog reference with motor loads disconnected. Look at driver responses, fault inputs and enable levels before trying a controlled load.

A changed shunt, divider or current-sense gain changes the conversion from ADC counts to engineering units. Compare the affected channel's raw reading and reference with the formulas in [sensing](sensing.md). A change in the module or timer configuration can also affect output timing.

(firmware-and-replacement-modules)=
## Firmware and controller service

The SoM is installed as part of QuadESC. The [mounting guide](assembly.md) covers clearance, cooling and programming access. The <a href="../som/maintenance.html">SoM service guide</a> covers module-specific rework checks.

Use an application suited to the mainboard's shared enables, driver connections and feedback routes. The [compatibility guide](characterization.md) describes the requirements for motor-control code, and the <a href="../som/boot.html">SoM boot guide</a> covers programming access.

## Getting help

Describe what you connected and what you observed. A supply voltage, load description and measurement point are useful for an electrical problem; a short sequence that reproduces the symptom helps with software behavior. Say whether a component reference belongs to the mainboard or the SoM: each board has its own U1, U2 and other designators.

## Glossary

| Term | Meaning |
|---|---|
| CSA | Current-sense amplifier inside the gate driver |
| Half bridge | High-side and low-side switching pair for one phase node |
| BEMF | Back electromotive force; also used in phase-voltage net names |
| Kelvin sense | Separate low-current sense connection to a current shunt |
| nFAULT | Active-low driver fault signal |
| FC | External flight controller |
| FOC | Field-oriented control |
| Nominal scale | Conversion formula using nominal component and reference values |

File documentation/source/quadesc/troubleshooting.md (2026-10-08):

# Troubleshooting and FAQ

Follow the signal from its source to the point where the result changes. The [connection guide](connections.md), [motor-control diagram](control.md) and [sensing formulas](sensing.md) help locate each part of that path.

## The board does not respond to flight-controller commands

The board ships with TI BSL only. Load a motor-control application with the FC's command decoder, then check J6 channel order, voltage levels and the configured protocol. [Flight-controller integration](integration.md) describes the signal paths; [first use](index.md#first-use) covers programming connections.

## A gate-driver register read fails

Check the selected chip-select line, driver supply and wake/enable state. All four drivers share the SPI signals, but each has its own chip select. Check the raw response before adjusting gain or other configuration. An internal MCU loopback check exercises the controller without sending a transaction to the external driver.

## Current looks plausible but has the wrong sign

The current-sense amplifier is inverting. Compare the sign with the definition and formula in [sensing](sensing.md), then check the reference and configured gain. A reversed sign can still produce plausible magnitudes while reversing the meaning of feedback. Looking at the raw code and the physical current path helps separate a sign error from a scale error.

## Phase voltage differs from the expected divider scale

The divider returns to the low-side source, so a ground-referenced voltage includes that node's contribution. Use the return-node correction in [sensing](sensing.md). Sampling time matters too: a sequential diagnostic scan reads the channels at different times rather than capturing a simultaneous waveform.

## Temperature rises while the raw count falls

That is the expected direction: lower counts mean a warmer board. The [nominal ADC-to-Celsius scale](sensing.md#board-temperature-from-the-thermistors) assumes a 10 kΩ thermistor at 25 °C and B = 3380 K; under those assumptions, 2048 counts is about 25 °C. Treat rail codes 0 and 4095 as invalid. Check the fitted sensor's curve, connection, VAA reference and selected channel before using the result for thermal control.

## A PWM command produces no measured waveform

Check the pad mux, peripheral power and clock, then trace the signal toward the driver. At the gate stage, check the common enables as well. Measuring at successive points helps distinguish a timer-output issue from an inactive driver.

## How much current can I run?

The [electrical targets](characterization.md) describe the intended design range. Usable current depends on cooling, ambient temperature and duration; the 40 A continuous and 70 A burst targets are not established operating ratings. Watch thermal behavior under the conditions of your assembled system.

## Which connector table should I use?

Use this manual's [PCB pad reference](connectors.md) for the mainboard and the <a href="../som/connectors.html">SoM pad reference</a> for module connectors. Check the connector name as well as its number because the boards have separate numbering.

For UART, CAN, the module power mux or boot recovery, use the <a href="../som/troubleshooting.html">SoM troubleshooting guide</a>.

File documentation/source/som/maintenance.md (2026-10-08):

# Care and service

Before replacing a module or changing a carrier connection, disconnect power and check the mating orientation, pinout and supply paths. The [connector reference](connectors.md) and [power diagram](power.md) are useful companions at the workbench.

## Firmware compatibility

A replacement module needs an application suited to its connected devices. Use [programming an application](firmware.md) for image layout and loading, and [boot and recovery](boot.md) for programming connections.

If a replacement module powers up but does not answer over UART, check the baud rate and boot mode before changing the hardware. [Troubleshooting](troubleshooting.md) covers the common checks.

## Assembly and service

The SoM front stencil is **100 µm**, with a **75 µm local step at U5**. When printing paste on the carrier's mating array, leave the SoM bottom LGA unprinted so the joint receives paste from one side. U2 and U6 thermal apertures are notched around unfilled vias.

After rework, inspect nearby joints and check continuity before applying power. Hidden LGA joints need an inspection method suited to the package. Then check the digital rail, VAA if used, and the interfaces affected by the repair before reconnecting external loads.

## Getting help

A short description of the symptom and the connection you are using is a good starting point. For a UART issue, the baud rate and a few lines of terminal output help explain what happened. For an electrical issue, describe the supply and where you measured. If a component number could refer to either board, say whether it is on the SoM or the carrier.

## Glossary

| Term | Meaning |
|---|---|
| SoM | System-on-module; the reusable controller assembly |
| Carrier | Board providing power, connectors and application circuitry |
| BSP / HAL | Board support / chip-level hardware abstraction code |
| Mux | Selection of one alternate function on a physical pad |
| BSL | MCU bootloader interface |
| VAA / VREFHI | Analog supply net / ADC high-reference net |
| LGA | Land grid array used for the underside solder interface |

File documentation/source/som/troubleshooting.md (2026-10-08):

# Troubleshooting and FAQ

Start with the active boot mode, power and wiring. A working SWD connection confirms digital access, but ADC and CAN also rely on separate supply connections.

## Why is the UART silent?

A newly received module has TI BSL only. Use a compatible BSL programmer to load an application; a serial terminal will not receive an application greeting. To invoke BSL, hold PA6 high during reset as described in [boot and recovery](boot.md).

For a loaded application, cross TX and RX, connect ground and match the baud rate and frame format to its code. Close other programs using the port. If it still does not start, inspect the reset handler and image layout over SWD.

## Why does CAN not respond?

Check the transceiver's 5 V rail, CANH/CANL wiring and termination. **PC0** controls the [termination switch](interfaces.md#can-termination-control). For ROM programming, use the CAN-FD settings and boot configuration in [boot and recovery](boot.md). For application traffic, match the configured bitrate and frame format to the other nodes.

## Why are ADC readings zero or near full scale?

Check the input connection and VAA/VREFHI first. A floating input, saturated divider or missing reference can make raw codes misleading. Follow the physical pad through its AIN identity to the selected ADC instance and channel. Compare input and reference voltages before applying the [conversion formula](analog.md#raw-counts-and-useful-units).

## Why does a timed output have the wrong period or stay driven after stop?

Check the timer's functional clock, prescaler, count mode and shared period. Stopping the counter does not necessarily release the pad. Configure the output actions and mux for the required idle state; see [timed outputs](timing.md).

## Is the whole side header a standard mikroBUS socket?

Each row has 12 pins, including CANH/CANL and additional signals and power connections. Use the [module pin table](connectors.md) to wire accessories.

(does-reset-reboot-the-module)=
## How do I reset the module?

Use `nRST` at J2.7 or a reset operation supported by your programmer. Reopening a terminal does not reset the MCU. PA6's level during reset selects whether you invoke BSL or start the programmed application.

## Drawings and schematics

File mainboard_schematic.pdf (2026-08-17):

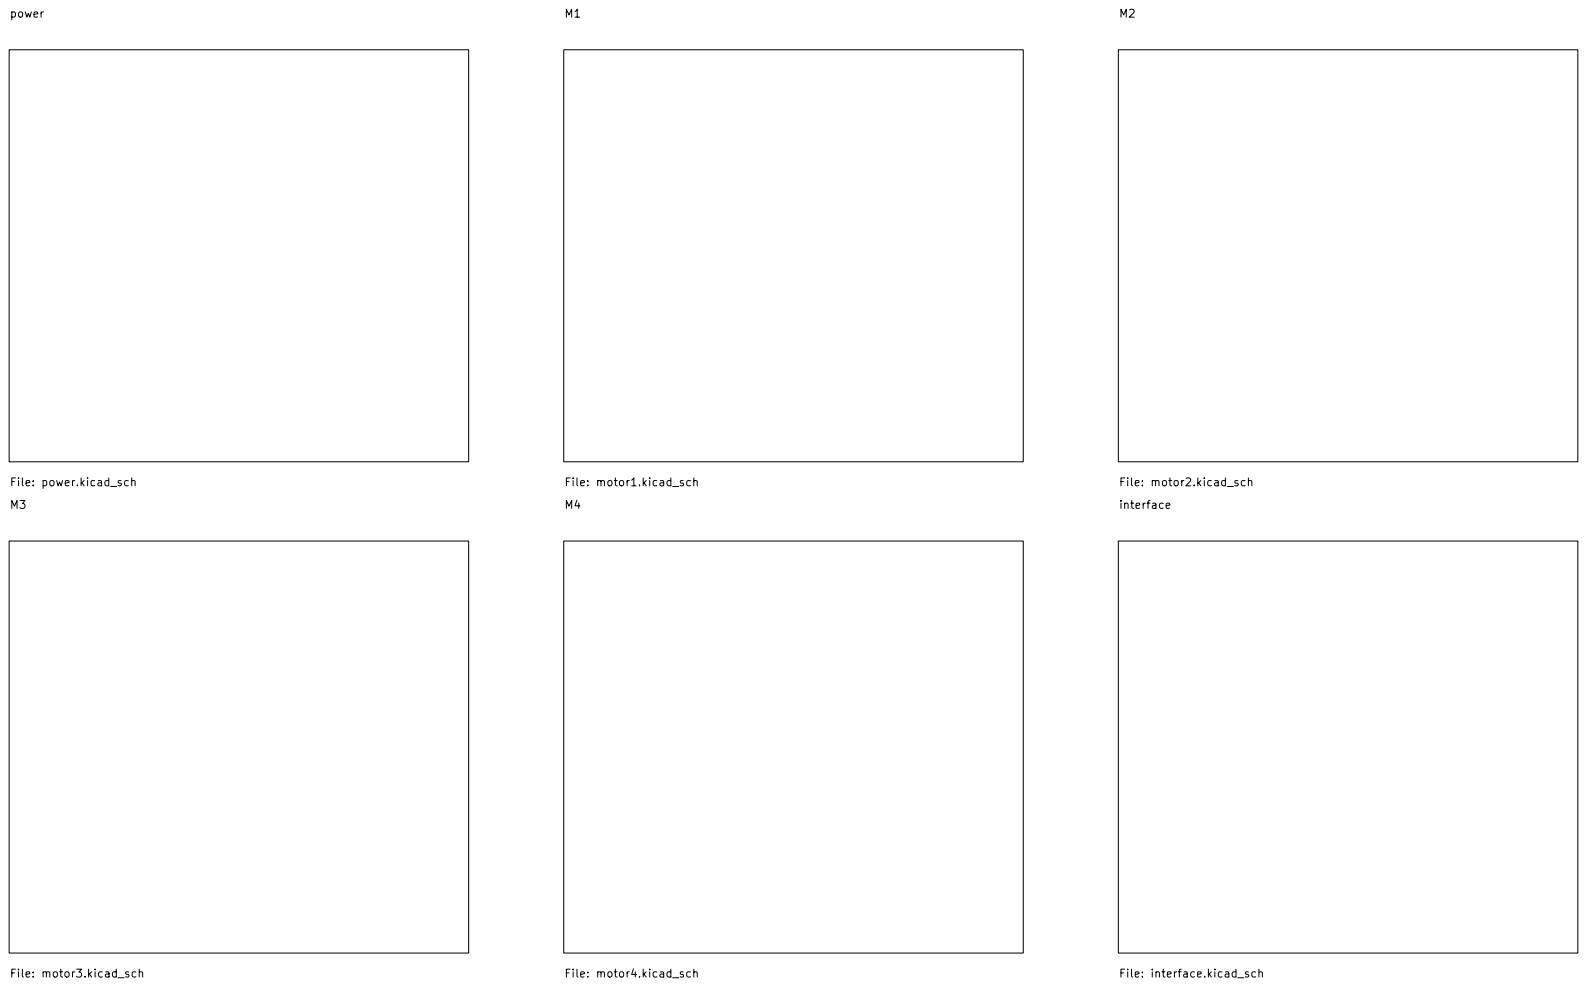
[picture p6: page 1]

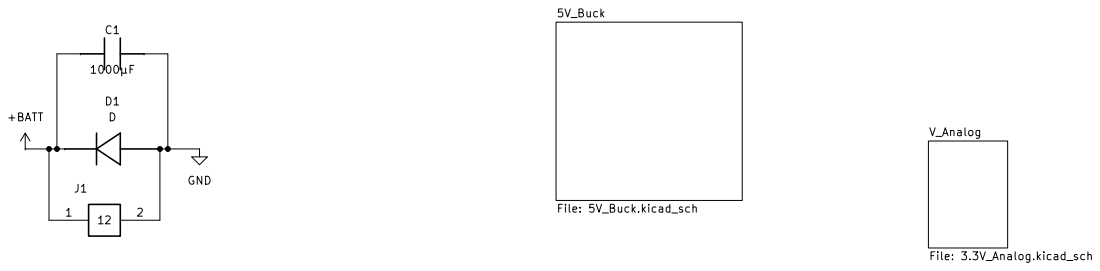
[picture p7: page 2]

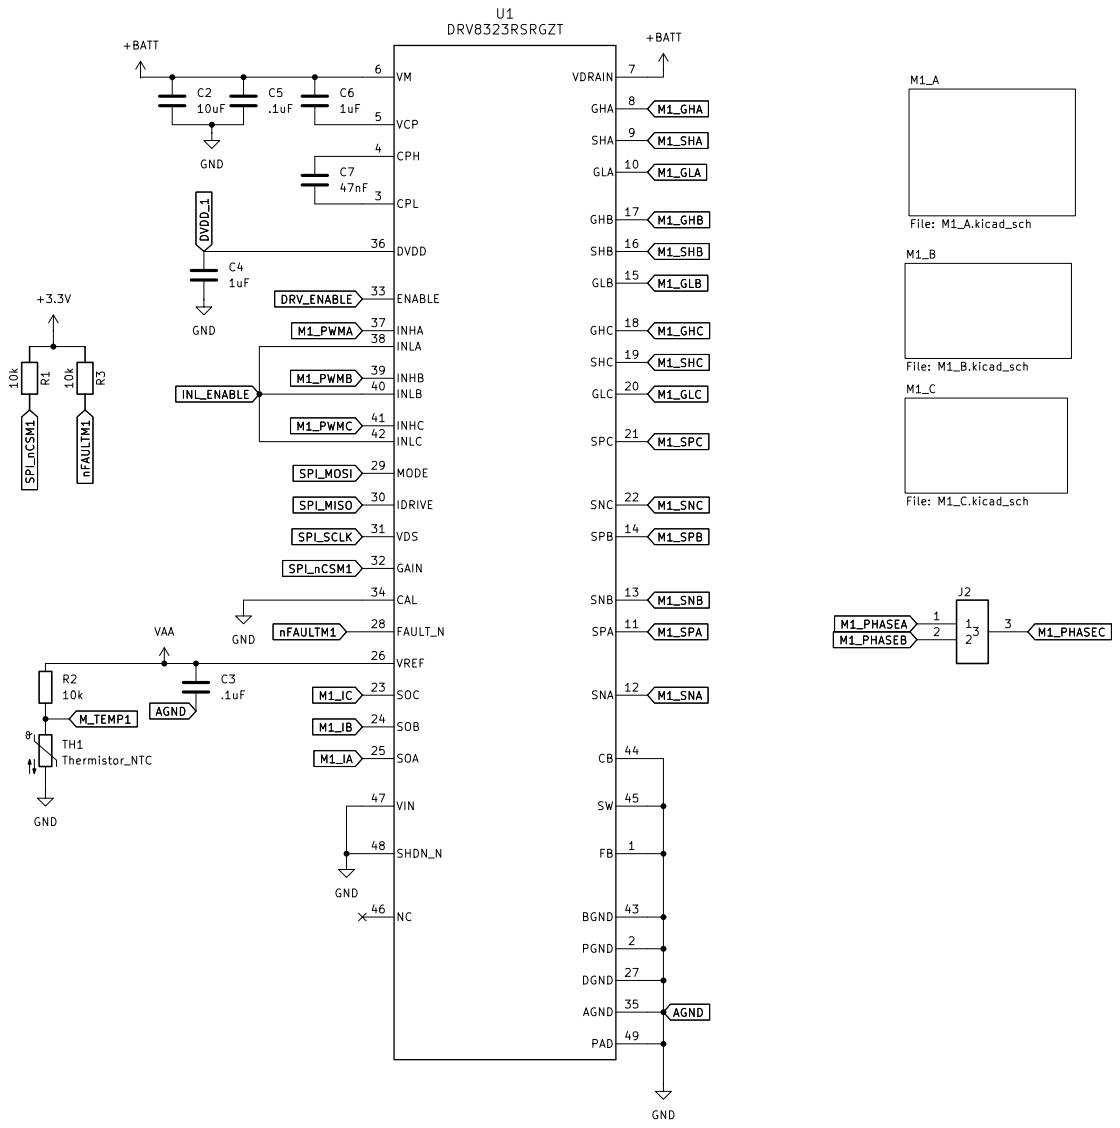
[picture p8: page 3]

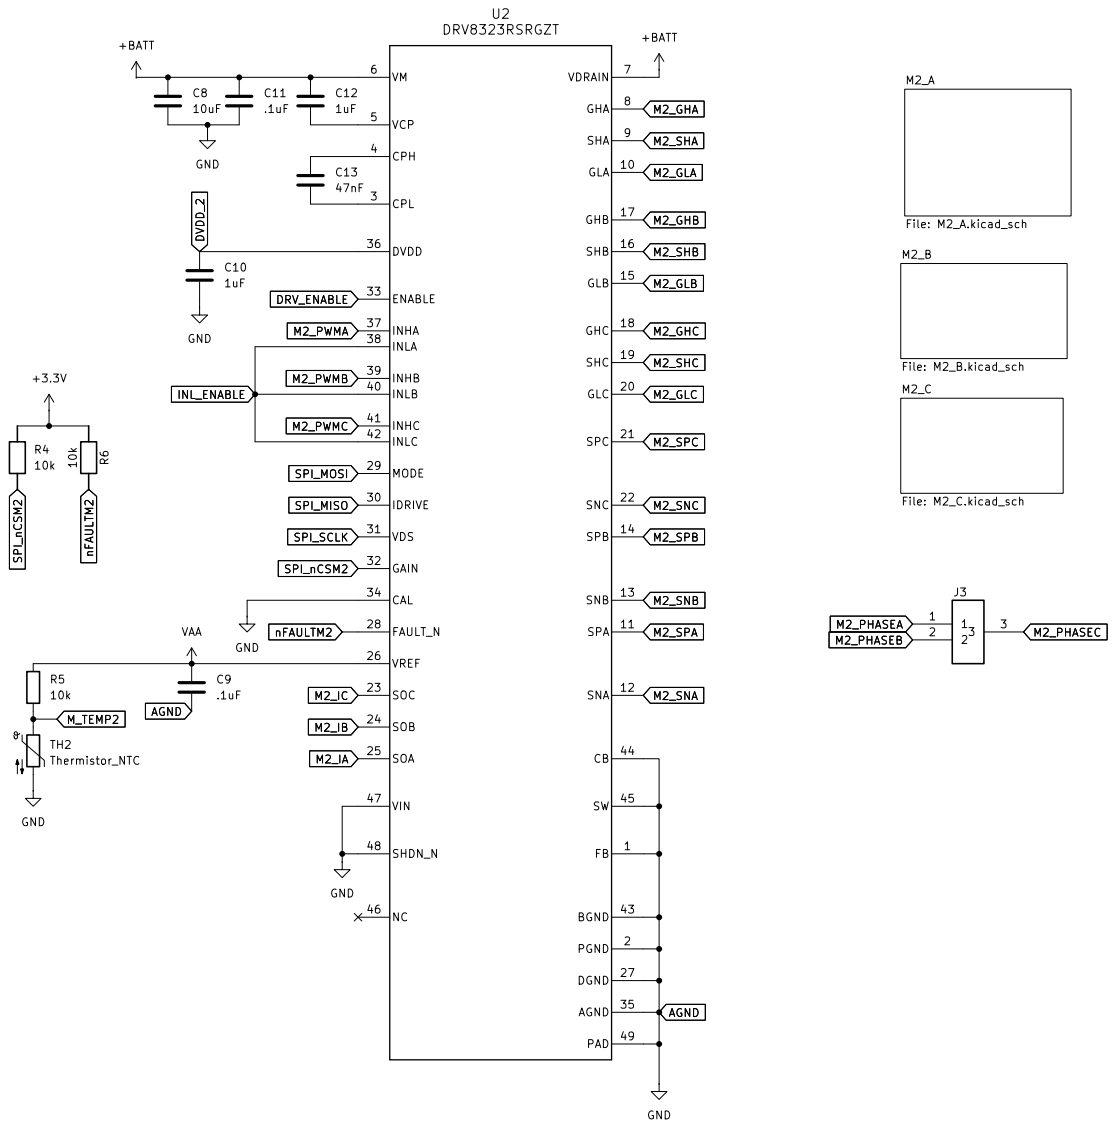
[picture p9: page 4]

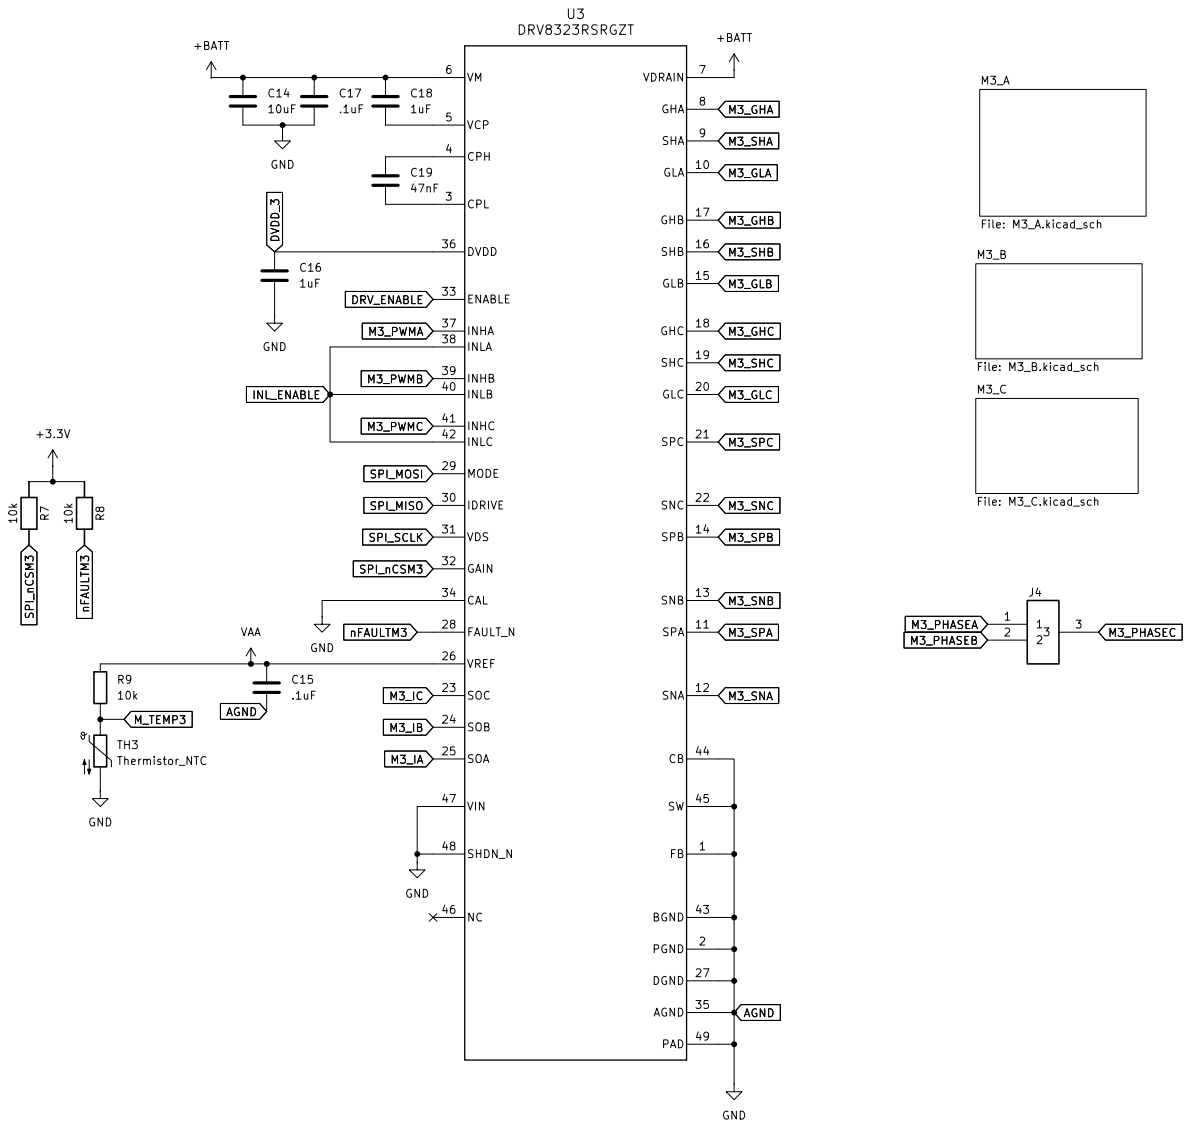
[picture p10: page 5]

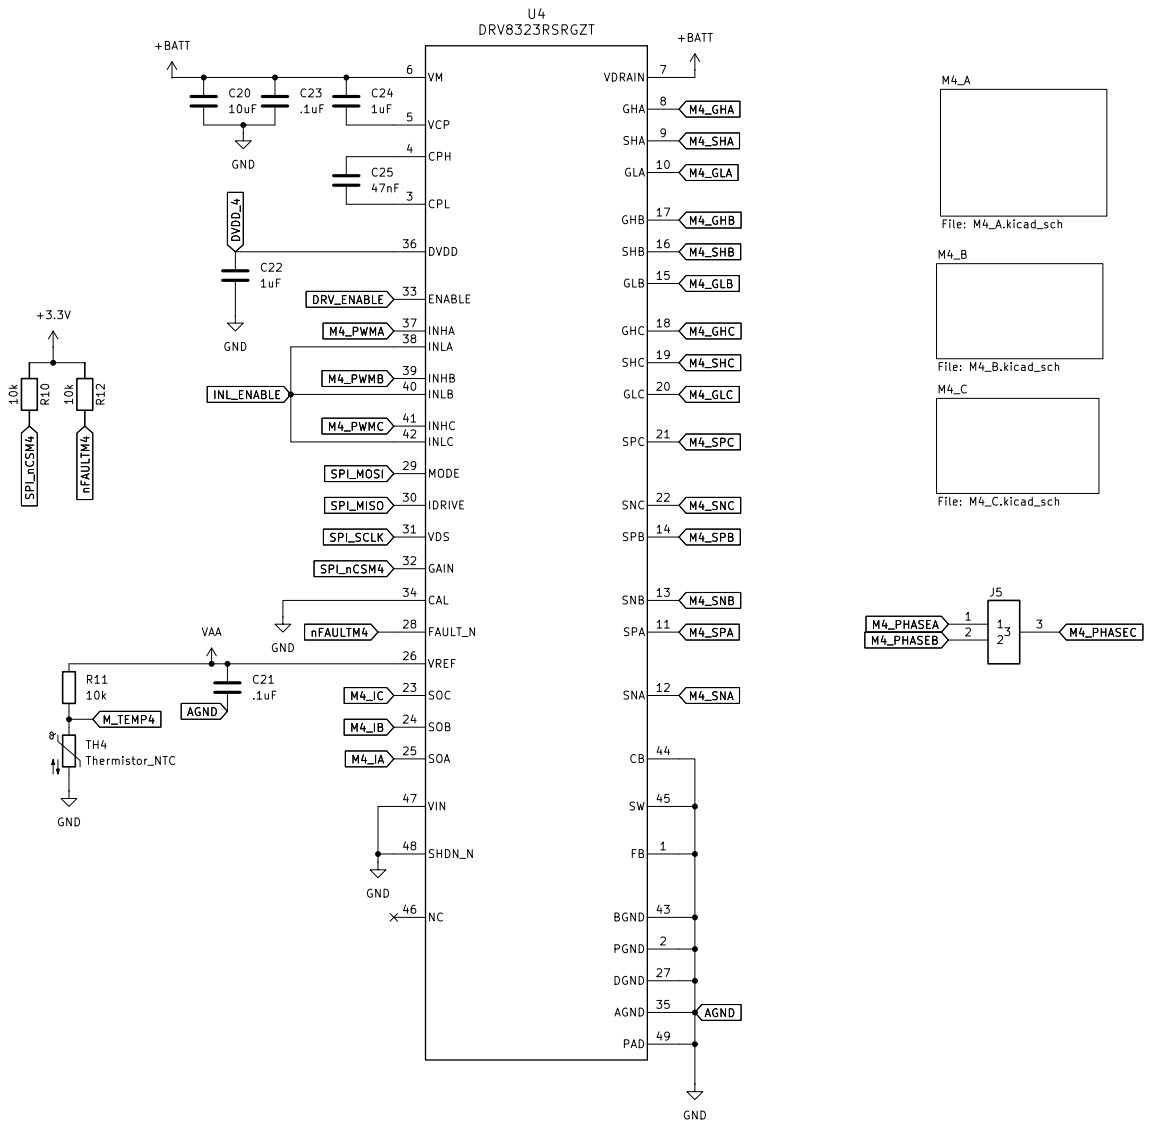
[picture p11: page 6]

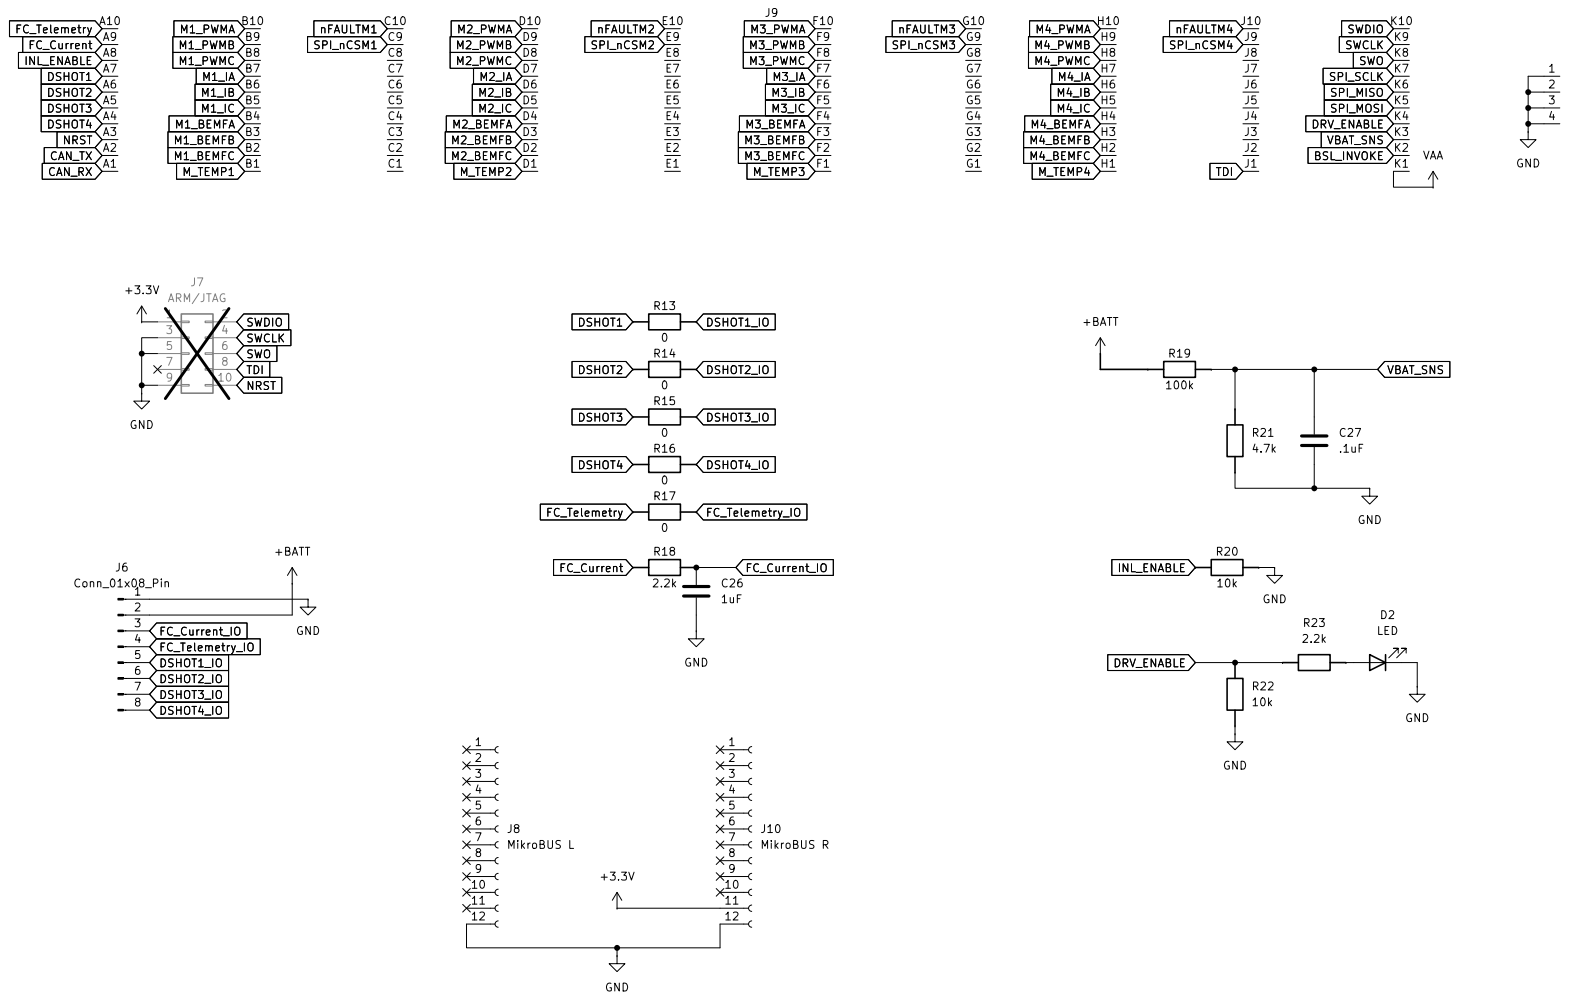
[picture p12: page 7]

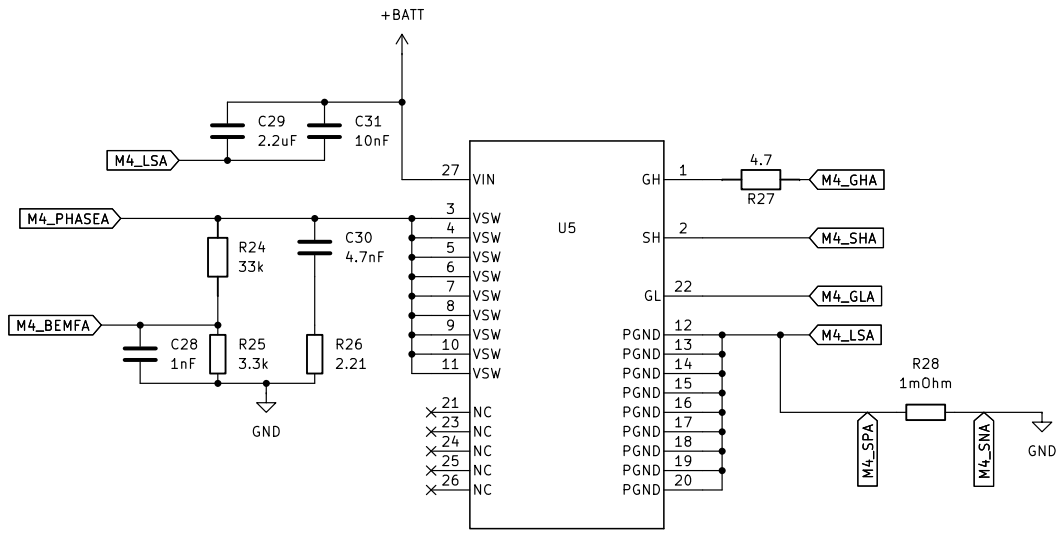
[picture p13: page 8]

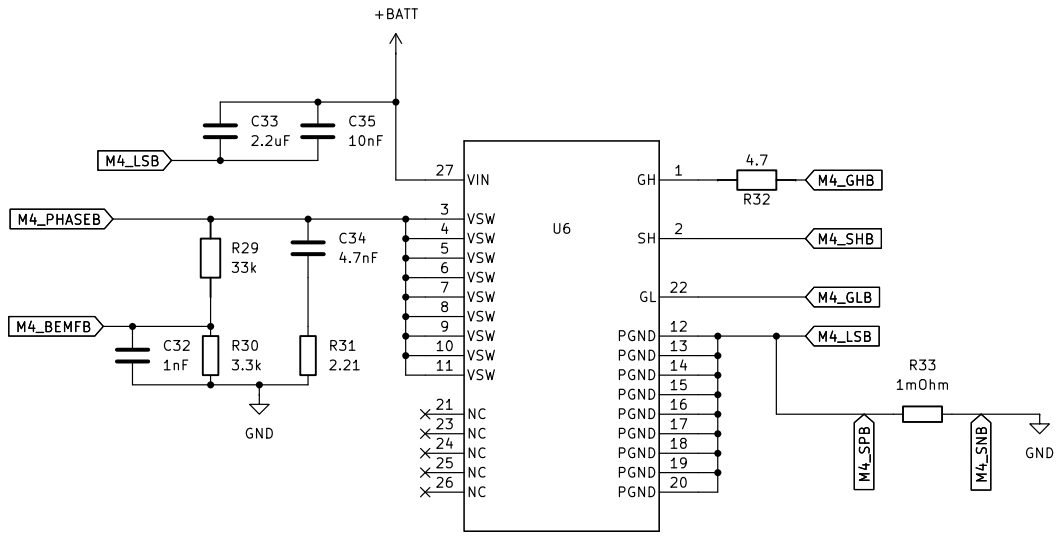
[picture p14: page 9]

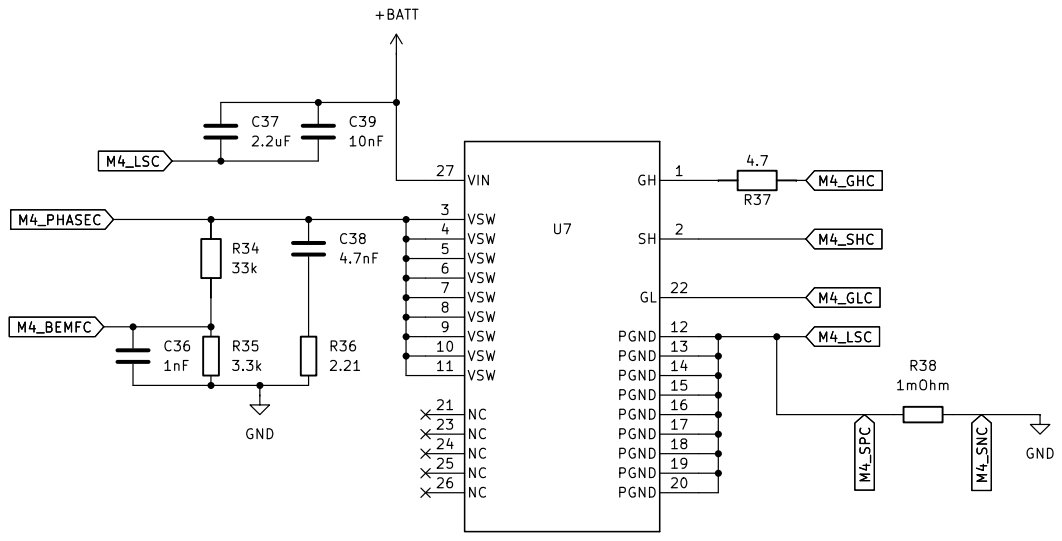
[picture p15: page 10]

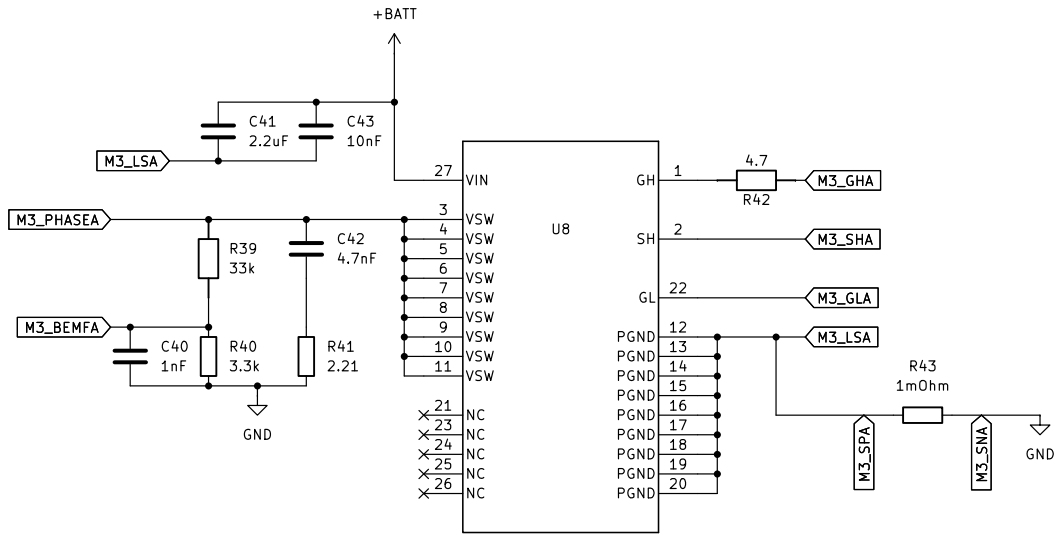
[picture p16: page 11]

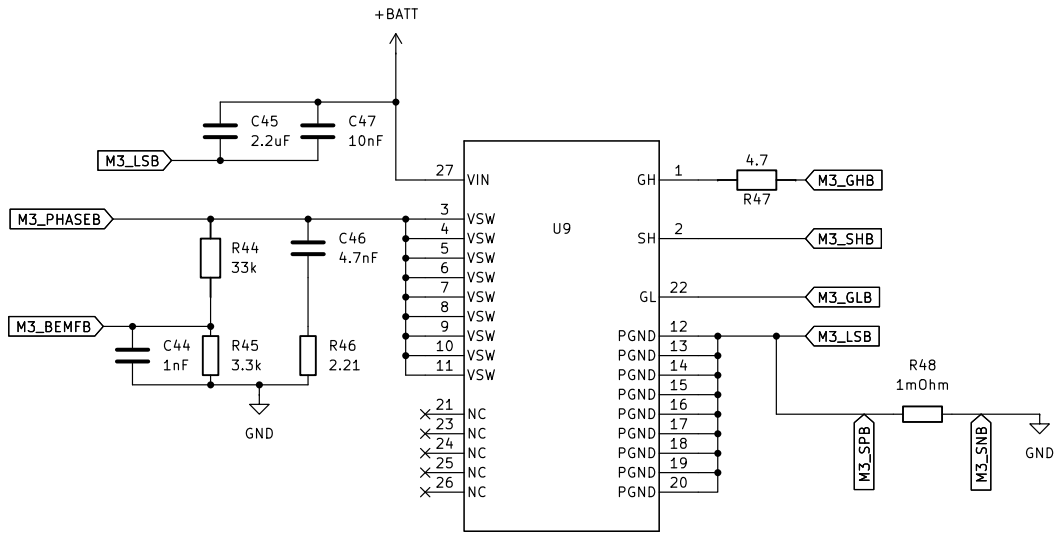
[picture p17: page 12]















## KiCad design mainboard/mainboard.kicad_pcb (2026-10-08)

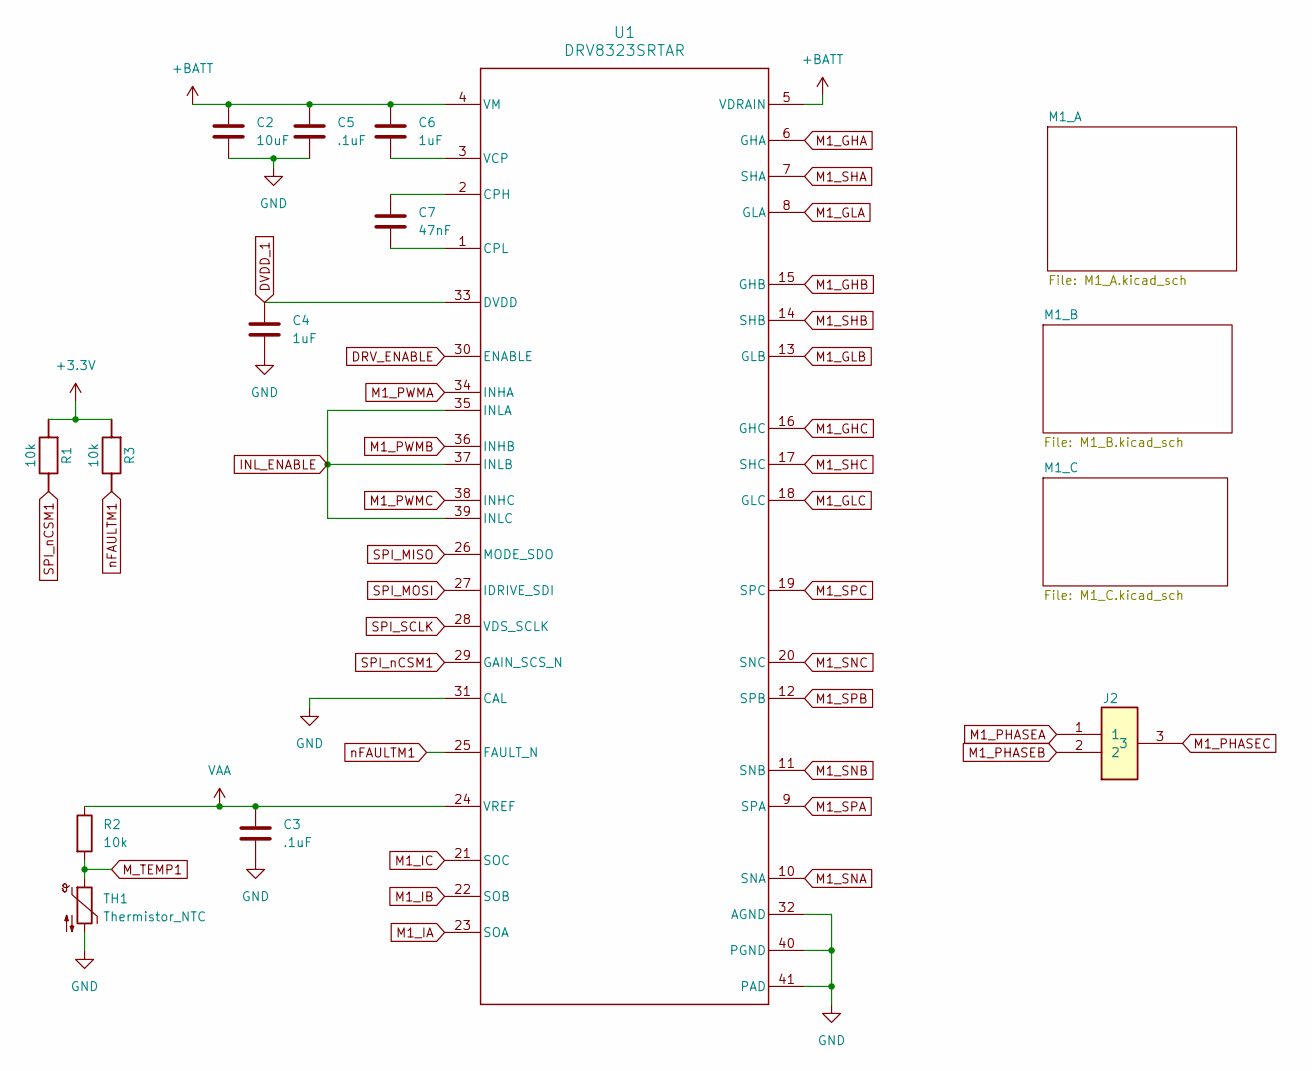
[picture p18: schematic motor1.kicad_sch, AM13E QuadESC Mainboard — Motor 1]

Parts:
C2: 10uF; C_1206_3216Metric
C3: .1uF; C_0201_0603Metric
C4: 1uF; C_0402_1005Metric
C5: .1uF; C_0402_1005Metric
C6: 1uF; C_0603_1608Metric
C7: 47nF; C_0402_1005Metric
J2: WirePad_Motor_3P_4.0x6.0_DualSide
R1, R2, R3: 10k; R_0201_0603Metric
TH1: Thermistor_NTC; R_0402_1005Metric
U1: DRV8323SRTAR; RTA0040B_NV

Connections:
+3.3V: R1.1, R3.1; also elsewhere on the board
+BATT: C2.1, C5.1, C6.1, U1.4 (VM), U1.5 (VDRAIN); also elsewhere on the board
DRV_ENABLE: U1.30 (ENABLE); also elsewhere on the board
DVDD_1: C4.1, U1.33 (DVDD)
GND: C2.2, C3.2, C4.2, C5.2, TH1.2, U1.31 (CAL), U1.32 (AGND), U1.40 (PGND), U1.41 (PAD); also elsewhere on the board
INL_ENABLE: U1.35 (INLA), U1.37 (INLB), U1.39 (INLC); also elsewhere on the board
M1_GHA: U1.6 (GHA); also elsewhere on the board
M1_GHB: U1.15 (GHB); also elsewhere on the board
M1_GHC: U1.16 (GHC); also elsewhere on the board
M1_GLA: U1.8 (GLA); also elsewhere on the board
M1_GLB: U1.13 (GLB); also elsewhere on the board
M1_GLC: U1.18 (GLC); also elsewhere on the board
M1_IA: U1.23 (SOA); also elsewhere on the board
M1_IB: U1.22 (SOB); also elsewhere on the board
M1_IC: U1.21 (SOC); also elsewhere on the board
M1_PHASEA: J2.1; also elsewhere on the board
M1_PHASEB: J2.2; also elsewhere on the board
M1_PHASEC: J2.3; also elsewhere on the board
M1_PWMA: U1.34 (INHA); also elsewhere on the board
M1_PWMB: U1.36 (INHB); also elsewhere on the board
M1_PWMC: U1.38 (INHC); also elsewhere on the board
M1_SHA: U1.7 (SHA); also elsewhere on the board
M1_SHB: U1.14 (SHB); also elsewhere on the board
M1_SHC: U1.17 (SHC); also elsewhere on the board
M1_SNA: U1.10 (SNA); also elsewhere on the board
M1_SNB: U1.11 (SNB); also elsewhere on the board
M1_SNC: U1.20 (SNC); also elsewhere on the board
M1_SPA: U1.9 (SPA); also elsewhere on the board
M1_SPB: U1.12 (SPB); also elsewhere on the board
M1_SPC: U1.19 (SPC); also elsewhere on the board
M_TEMP1: R2.2, TH1.1; also elsewhere on the board
unnamed: C7.1, U1.2 (CPH)
unnamed: C7.2, U1.1 (CPL)
unnamed: C6.2, U1.3 (VCP)
SPI_MISO: U1.26 (MODE_SDO); also elsewhere on the board
SPI_MOSI: U1.27 (IDRIVE_SDI); also elsewhere on the board
SPI_SCLK: U1.28 (VDS_SCLK); also elsewhere on the board
SPI_nCSM1: R1.2, U1.29 (GAIN_SCS_N); also elsewhere on the board
VAA: C3.1, R2.1, U1.24 (VREF); also elsewhere on the board
nFAULTM1: R3.2, U1.25 (FAULT_N); also elsewhere on the board

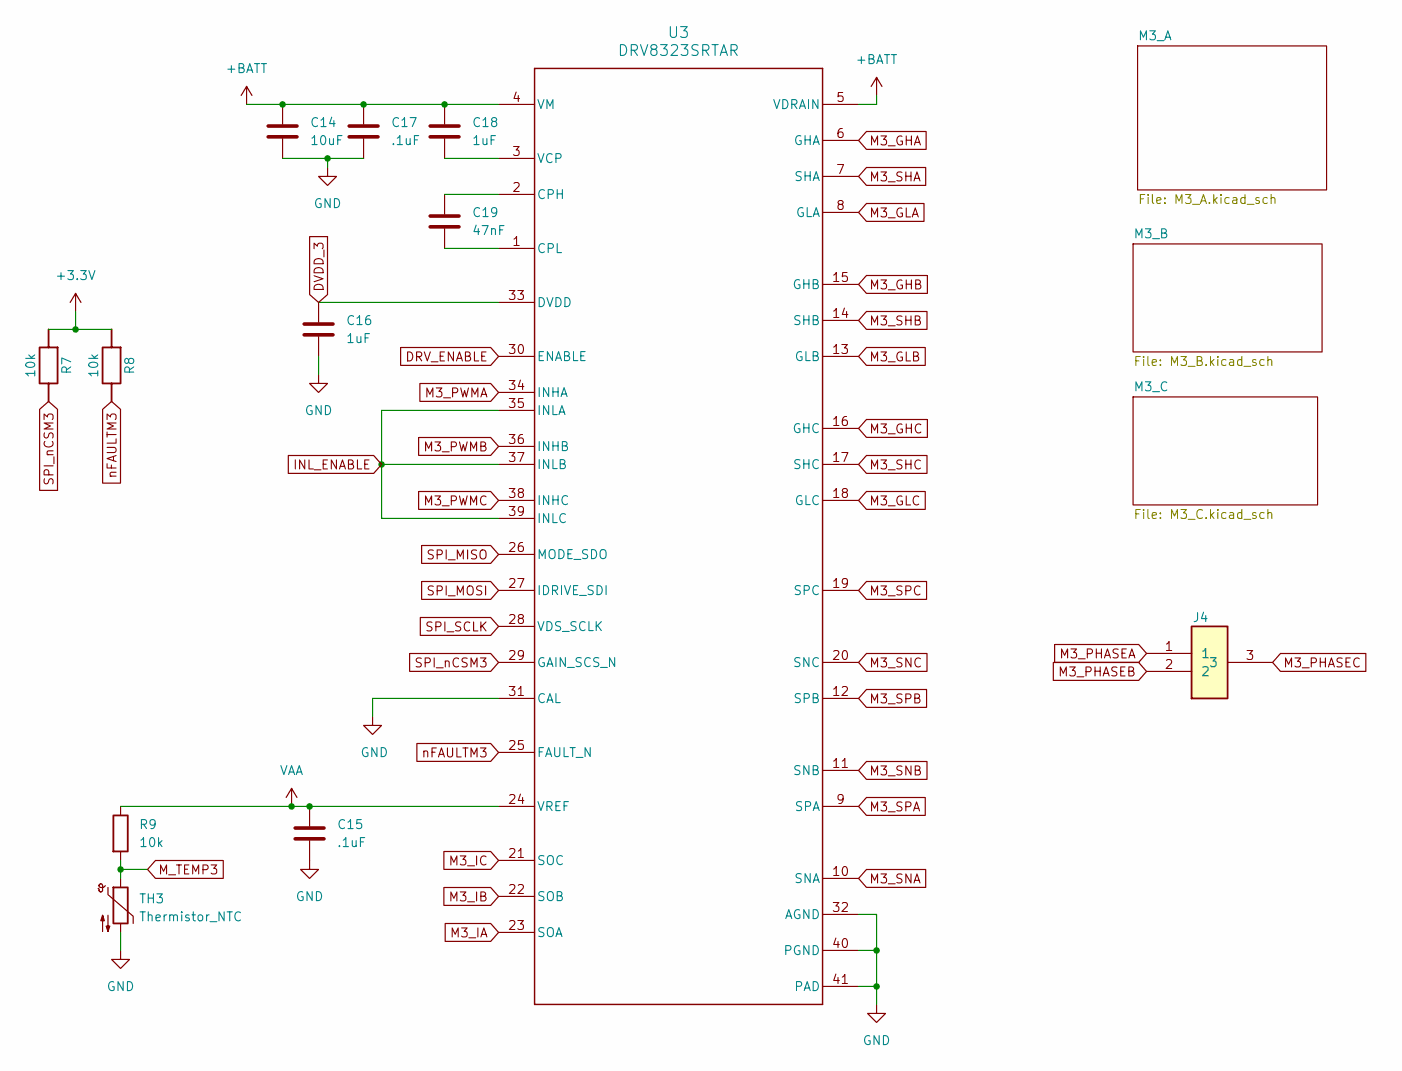
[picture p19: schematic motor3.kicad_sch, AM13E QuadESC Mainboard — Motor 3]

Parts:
C14: 10uF; C_1206_3216Metric
C15: .1uF; C_0201_0603Metric
C16: 1uF; C_0402_1005Metric
C17: .1uF; C_0402_1005Metric
C18: 1uF; C_0603_1608Metric
C19: 47nF; C_0402_1005Metric
J4: WirePad_Motor_3P_4.0x6.0_DualSide
R7, R8, R9: 10k; R_0201_0603Metric
TH3: Thermistor_NTC; R_0402_1005Metric
U3: DRV8323SRTAR; RTA0040B_NV

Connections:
+3.3V: R7.1, R8.1; also elsewhere on the board
+BATT: C14.1, C17.1, C18.1, U3.4 (VM), U3.5 (VDRAIN); also elsewhere on the board
DRV_ENABLE: U3.30 (ENABLE); also elsewhere on the board
DVDD_3: C16.1, U3.33 (DVDD)
GND: C14.2, C15.2, C16.2, C17.2, TH3.2, U3.31 (CAL), U3.32 (AGND), U3.40 (PGND), U3.41 (PAD); also elsewhere on the board
INL_ENABLE: U3.35 (INLA), U3.37 (INLB), U3.39 (INLC); also elsewhere on the board
M3_GHA: U3.6 (GHA); also elsewhere on the board
M3_GHB: U3.15 (GHB); also elsewhere on the board
M3_GHC: U3.16 (GHC); also elsewhere on the board
M3_GLA: U3.8 (GLA); also elsewhere on the board
M3_GLB: U3.13 (GLB); also elsewhere on the board
M3_GLC: U3.18 (GLC); also elsewhere on the board
M3_IA: U3.23 (SOA); also elsewhere on the board
M3_IB: U3.22 (SOB); also elsewhere on the board
M3_IC: U3.21 (SOC); also elsewhere on the board
M3_PHASEA: J4.1; also elsewhere on the board
M3_PHASEB: J4.2; also elsewhere on the board
M3_PHASEC: J4.3; also elsewhere on the board
M3_PWMA: U3.34 (INHA); also elsewhere on the board
M3_PWMB: U3.36 (INHB); also elsewhere on the board
M3_PWMC: U3.38 (INHC); also elsewhere on the board
M3_SHA: U3.7 (SHA); also elsewhere on the board
M3_SHB: U3.14 (SHB); also elsewhere on the board
M3_SHC: U3.17 (SHC); also elsewhere on the board
M3_SNA: U3.10 (SNA); also elsewhere on the board
M3_SNB: U3.11 (SNB); also elsewhere on the board
M3_SNC: U3.20 (SNC); also elsewhere on the board
M3_SPA: U3.9 (SPA); also elsewhere on the board
M3_SPB: U3.12 (SPB); also elsewhere on the board
M3_SPC: U3.19 (SPC); also elsewhere on the board
M_TEMP3: R9.2, TH3.1; also elsewhere on the board
unnamed: C19.1, U3.2 (CPH)
unnamed: C19.2, U3.1 (CPL)
unnamed: C18.2, U3.3 (VCP)
SPI_MISO: U3.26 (MODE_SDO); also elsewhere on the board
SPI_MOSI: U3.27 (IDRIVE_SDI); also elsewhere on the board
SPI_SCLK: U3.28 (VDS_SCLK); also elsewhere on the board
SPI_nCSM3: R7.2, U3.29 (GAIN_SCS_N); also elsewhere on the board
VAA: C15.1, R9.1, U3.24 (VREF); also elsewhere on the board
nFAULTM3: R8.2, U3.25 (FAULT_N); also elsewhere on the board

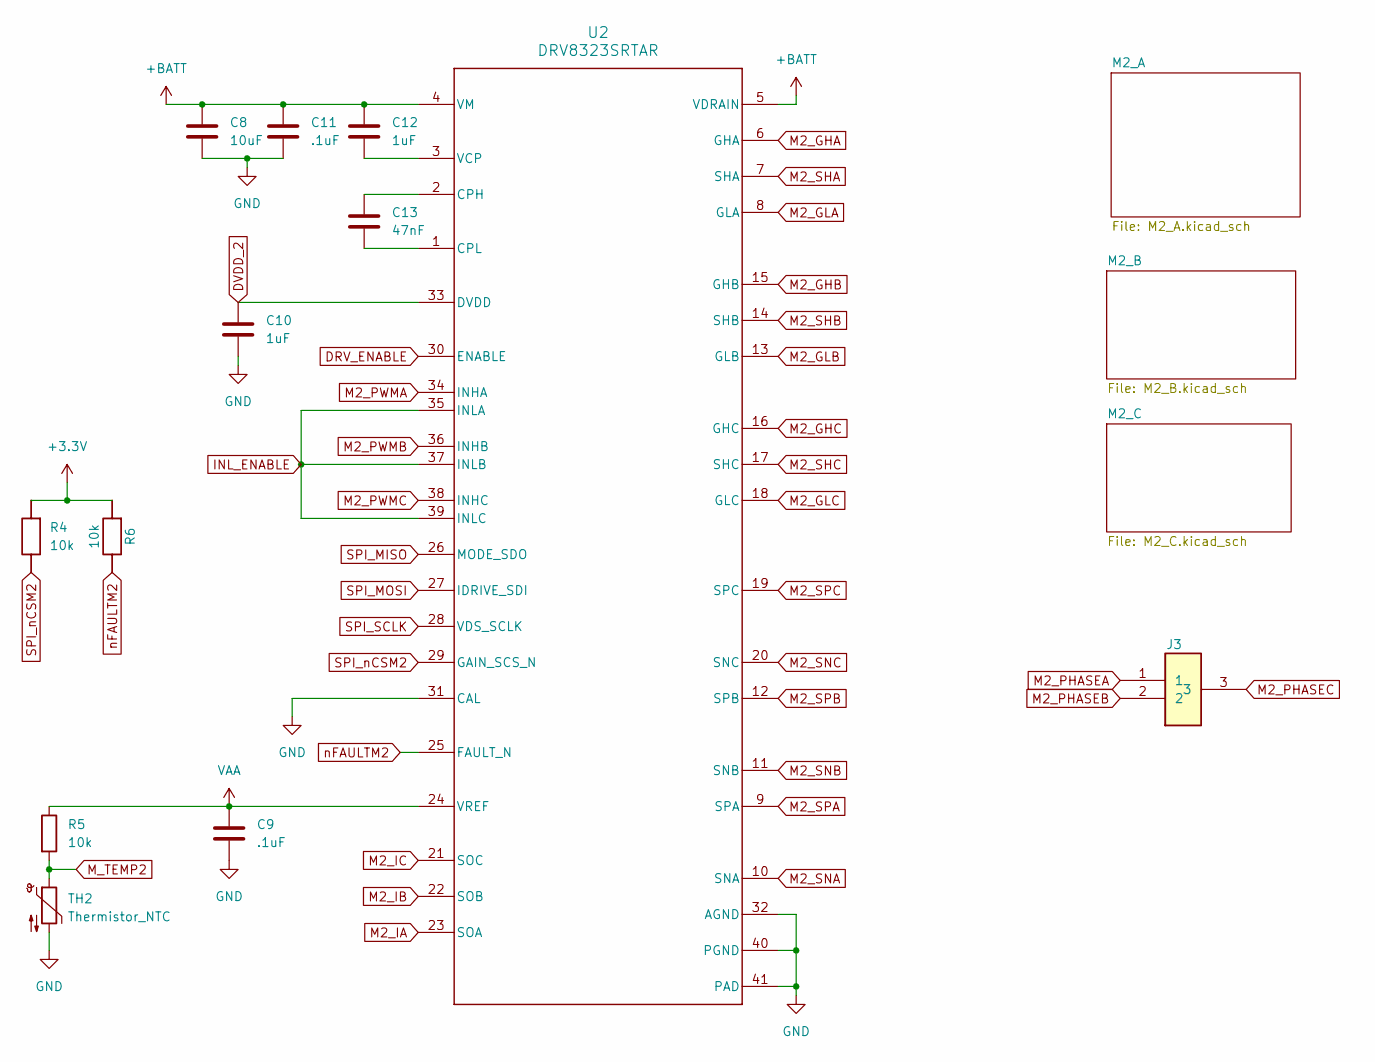
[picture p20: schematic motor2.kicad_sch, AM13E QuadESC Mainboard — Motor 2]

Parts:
C8: 10uF; C_1206_3216Metric
C9: .1uF; C_0201_0603Metric
C10: 1uF; C_0402_1005Metric
C11: .1uF; C_0402_1005Metric
C12: 1uF; C_0603_1608Metric
C13: 47nF; C_0402_1005Metric
J3: WirePad_Motor_3P_4.0x6.0_DualSide
R4, R5, R6: 10k; R_0201_0603Metric
TH2: Thermistor_NTC; R_0402_1005Metric
U2: DRV8323SRTAR; RTA0040B_NV

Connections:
+3.3V: R4.1, R6.1; also elsewhere on the board
+BATT: C8.1, C11.1, C12.1, U2.4 (VM), U2.5 (VDRAIN); also elsewhere on the board
DRV_ENABLE: U2.30 (ENABLE); also elsewhere on the board
DVDD_2: C10.1, U2.33 (DVDD)
GND: C8.2, C9.2, C10.2, C11.2, TH2.2, U2.31 (CAL), U2.32 (AGND), U2.40 (PGND), U2.41 (PAD); also elsewhere on the board
INL_ENABLE: U2.35 (INLA), U2.37 (INLB), U2.39 (INLC); also elsewhere on the board
M2_GHA: U2.6 (GHA); also elsewhere on the board
M2_GHB: U2.15 (GHB); also elsewhere on the board
M2_GHC: U2.16 (GHC); also elsewhere on the board
M2_GLA: U2.8 (GLA); also elsewhere on the board
M2_GLB: U2.13 (GLB); also elsewhere on the board
M2_GLC: U2.18 (GLC); also elsewhere on the board
M2_IA: U2.23 (SOA); also elsewhere on the board
M2_IB: U2.22 (SOB); also elsewhere on the board
M2_IC: U2.21 (SOC); also elsewhere on the board
M2_PHASEA: J3.1; also elsewhere on the board
M2_PHASEB: J3.2; also elsewhere on the board
M2_PHASEC: J3.3; also elsewhere on the board
M2_PWMA: U2.34 (INHA); also elsewhere on the board
M2_PWMB: U2.36 (INHB); also elsewhere on the board
M2_PWMC: U2.38 (INHC); also elsewhere on the board
M2_SHA: U2.7 (SHA); also elsewhere on the board
M2_SHB: U2.14 (SHB); also elsewhere on the board
M2_SHC: U2.17 (SHC); also elsewhere on the board
M2_SNA: U2.10 (SNA); also elsewhere on the board
M2_SNB: U2.11 (SNB); also elsewhere on the board
M2_SNC: U2.20 (SNC); also elsewhere on the board
M2_SPA: U2.9 (SPA); also elsewhere on the board
M2_SPB: U2.12 (SPB); also elsewhere on the board
M2_SPC: U2.19 (SPC); also elsewhere on the board
M_TEMP2: R5.2, TH2.1; also elsewhere on the board
unnamed: C13.1, U2.2 (CPH)
unnamed: C13.2, U2.1 (CPL)
unnamed: C12.2, U2.3 (VCP)
SPI_MISO: U2.26 (MODE_SDO); also elsewhere on the board
SPI_MOSI: U2.27 (IDRIVE_SDI); also elsewhere on the board
SPI_SCLK: U2.28 (VDS_SCLK); also elsewhere on the board
SPI_nCSM2: R4.2, U2.29 (GAIN_SCS_N); also elsewhere on the board
VAA: C9.1, R5.1, U2.24 (VREF); also elsewhere on the board
nFAULTM2: R6.2, U2.25 (FAULT_N); also elsewhere on the board

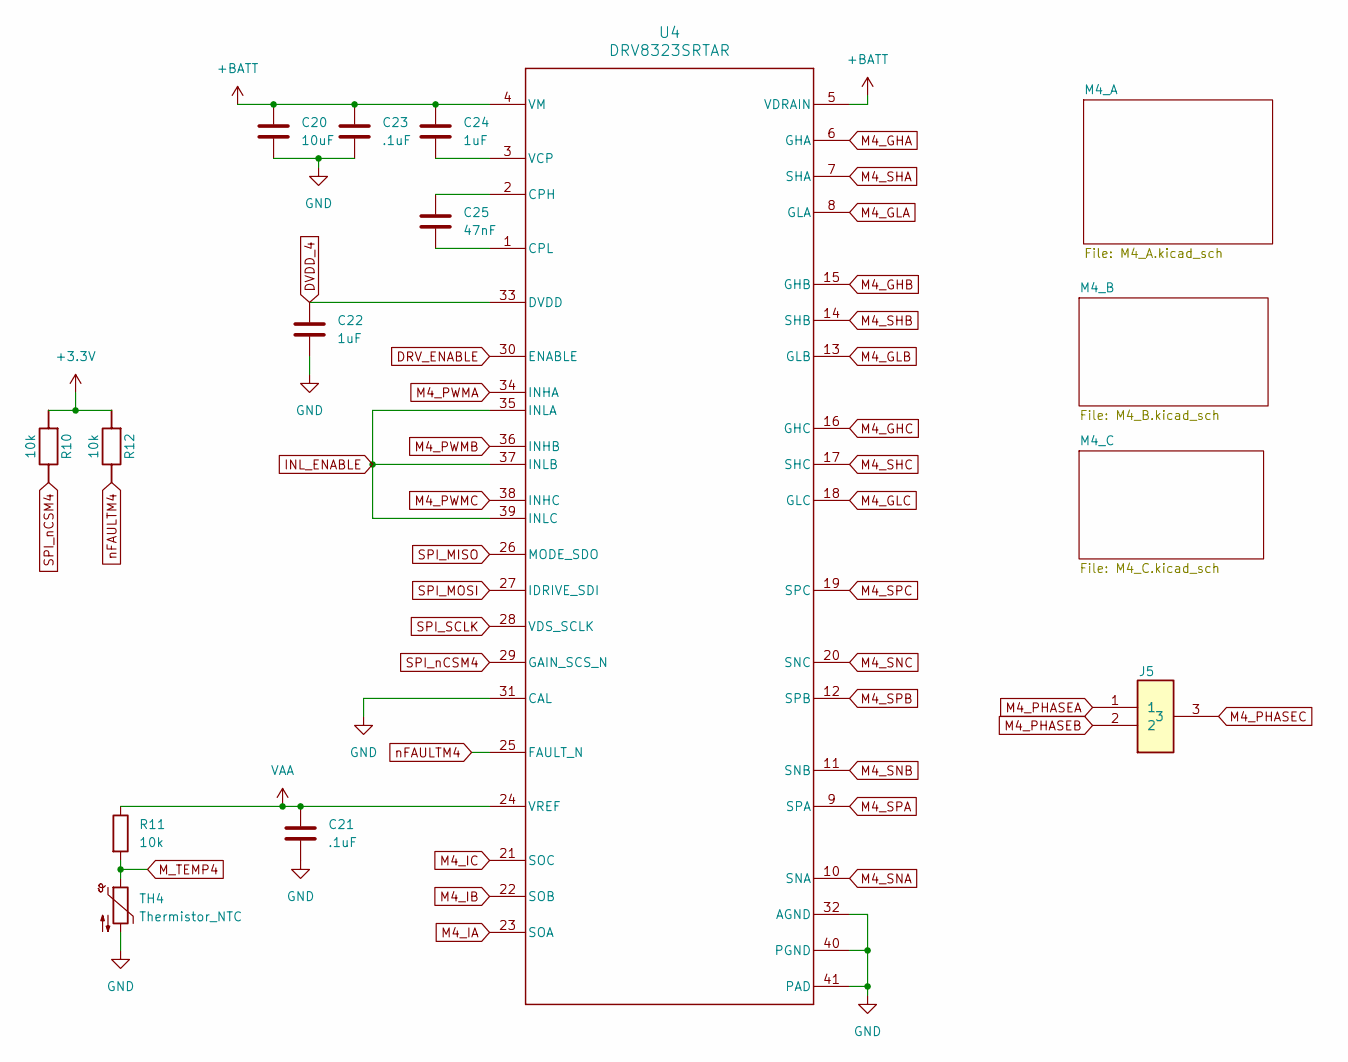
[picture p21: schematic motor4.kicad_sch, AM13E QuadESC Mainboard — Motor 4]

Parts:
C20: 10uF; C_1206_3216Metric
C21: .1uF; C_0201_0603Metric
C22: 1uF; C_0402_1005Metric
C23: .1uF; C_0402_1005Metric
C24: 1uF; C_0603_1608Metric
C25: 47nF; C_0402_1005Metric
J5: WirePad_Motor_3P_4.0x6.0_DualSide
R10, R11, R12: 10k; R_0201_0603Metric
TH4: Thermistor_NTC; R_0402_1005Metric
U4: DRV8323SRTAR; RTA0040B_NV

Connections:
+3.3V: R10.1, R12.1; also elsewhere on the board
+BATT: C20.1, C23.1, C24.1, U4.4 (VM), U4.5 (VDRAIN); also elsewhere on the board
DRV_ENABLE: U4.30 (ENABLE); also elsewhere on the board
DVDD_4: C22.1, U4.33 (DVDD)
GND: C20.2, C21.2, C22.2, C23.2, TH4.2, U4.31 (CAL), U4.32 (AGND), U4.40 (PGND), U4.41 (PAD); also elsewhere on the board
INL_ENABLE: U4.35 (INLA), U4.37 (INLB), U4.39 (INLC); also elsewhere on the board
M4_GHA: U4.6 (GHA); also elsewhere on the board
M4_GHB: U4.15 (GHB); also elsewhere on the board
M4_GHC: U4.16 (GHC); also elsewhere on the board
M4_GLA: U4.8 (GLA); also elsewhere on the board
M4_GLB: U4.13 (GLB); also elsewhere on the board
M4_GLC: U4.18 (GLC); also elsewhere on the board
M4_IA: U4.23 (SOA); also elsewhere on the board
M4_IB: U4.22 (SOB); also elsewhere on the board
M4_IC: U4.21 (SOC); also elsewhere on the board
M4_PHASEA: J5.1; also elsewhere on the board
M4_PHASEB: J5.2; also elsewhere on the board
M4_PHASEC: J5.3; also elsewhere on the board
M4_PWMA: U4.34 (INHA); also elsewhere on the board
M4_PWMB: U4.36 (INHB); also elsewhere on the board
M4_PWMC: U4.38 (INHC); also elsewhere on the board
M4_SHA: U4.7 (SHA); also elsewhere on the board
M4_SHB: U4.14 (SHB); also elsewhere on the board
M4_SHC: U4.17 (SHC); also elsewhere on the board
M4_SNA: U4.10 (SNA); also elsewhere on the board
M4_SNB: U4.11 (SNB); also elsewhere on the board
M4_SNC: U4.20 (SNC); also elsewhere on the board
M4_SPA: U4.9 (SPA); also elsewhere on the board
M4_SPB: U4.12 (SPB); also elsewhere on the board
M4_SPC: U4.19 (SPC); also elsewhere on the board
M_TEMP4: R11.2, TH4.1; also elsewhere on the board
unnamed: C25.1, U4.2 (CPH)
unnamed: C25.2, U4.1 (CPL)
unnamed: C24.2, U4.3 (VCP)
SPI_MISO: U4.26 (MODE_SDO); also elsewhere on the board
SPI_MOSI: U4.27 (IDRIVE_SDI); also elsewhere on the board
SPI_SCLK: U4.28 (VDS_SCLK); also elsewhere on the board
SPI_nCSM4: R10.2, U4.29 (GAIN_SCS_N); also elsewhere on the board
VAA: C21.1, R11.1, U4.24 (VREF); also elsewhere on the board
nFAULTM4: R12.2, U4.25 (FAULT_N); also elsewhere on the board

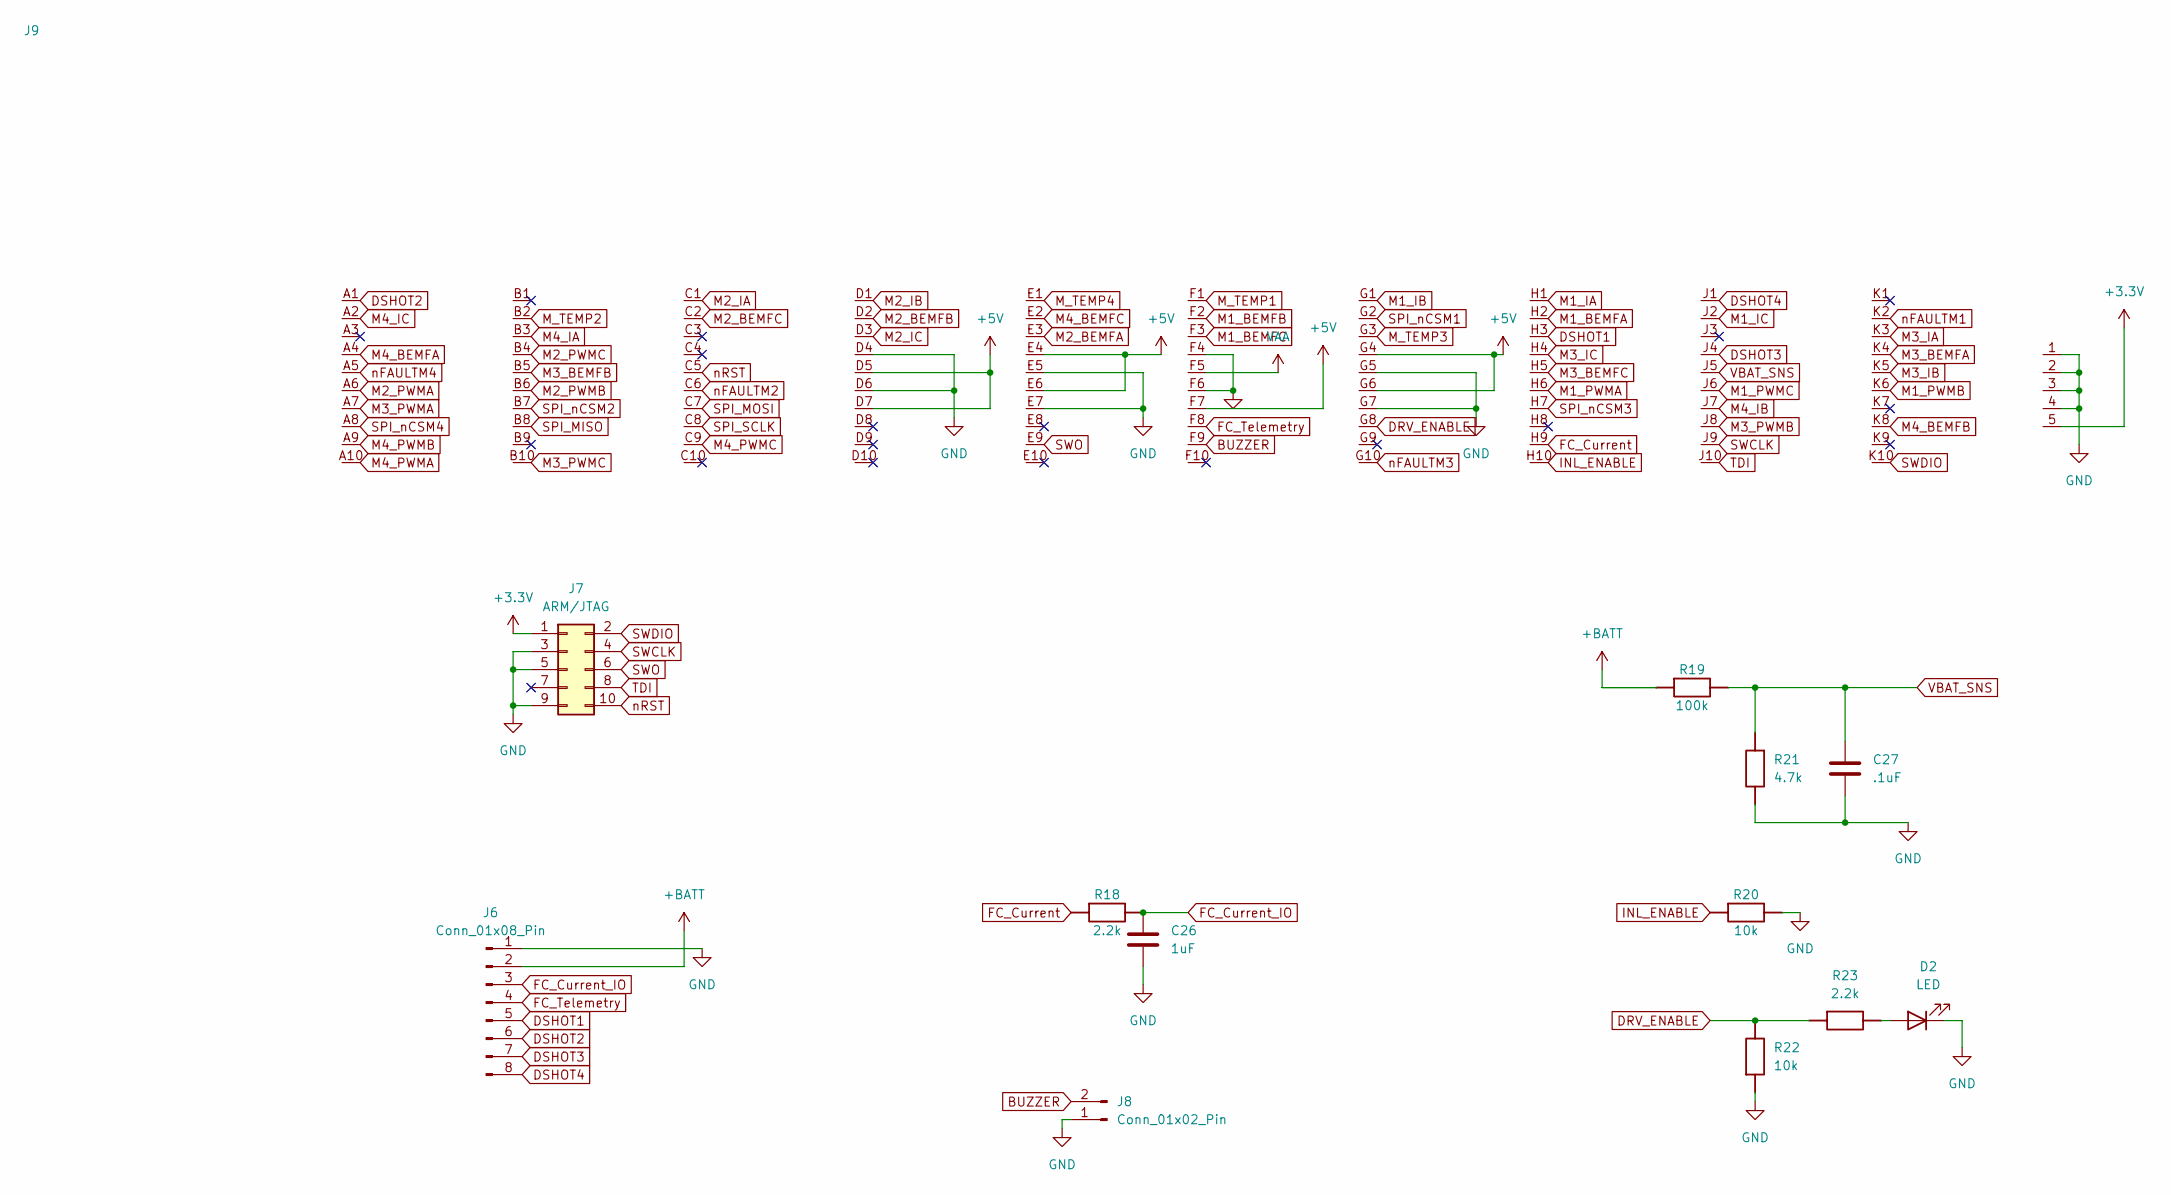
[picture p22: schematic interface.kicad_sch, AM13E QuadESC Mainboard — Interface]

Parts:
C26: 1uF; C_0402_1005Metric
C27: .1uF; C_0201_0603Metric
D2: LED; LED_0402_1005Metric
J6: Conn_01x08_Pin; JST_SM08B-SRSS-TB
J7: ARM/JTAG; PinHeader_2x05_P1.27mm_Vertical_SMD
J8: Conn_01x02_Pin; PinHeader_1x02_P1.00mm_Vertical
J9: AM13E_SoM_Receptacle_LGA100
R18, R23: 2.2k; R_0201_0603Metric
R19: 100k; R_0402_1005Metric
R20, R22: 10k; R_0201_0603Metric
R21: 4.7k; R_0201_0603Metric

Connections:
+3.3V: J7.1, J9.5; also elsewhere on the board
+BATT: J6.2, R19.1; also elsewhere on the board
BUCK_OUT: J9.D5, J9.D7, J9.E4, J9.E6, J9.F7, J9.G4, J9.G6; also elsewhere on the board
BUZZER: J8.2, J9.F9
DRV_ENABLE: J9.G8, R22.2, R23.1; also elsewhere on the board
DSHOT1: J6.5, J9.H3
DSHOT2: J6.6, J9.A1
DSHOT3: J6.7, J9.J4
DSHOT4: J6.8, J9.J1
FC_Current: J9.H9, R18.1
FC_Current_IO: C26.1, J6.3, R18.2
FC_Telemetry: J6.4, J9.F8
GND: C26.2, C27.2, D2.1 (K), J6.1, J7.3, J7.5, J7.9, J8.1, J9.1, J9.2, J9.3, J9.4, J9.D4, J9.D6, J9.E5, J9.E7, J9.F4, J9.F6, J9.G5, J9.G7, R20.2, R21.2, R22.1; also elsewhere on the board
INL_ENABLE: J9.H10, R20.1; also elsewhere on the board
M1_BEMFA: J9.H2; also elsewhere on the board
M1_BEMFB: J9.F2; also elsewhere on the board
M1_BEMFC: J9.F3; also elsewhere on the board
M1_IA: J9.H1; also elsewhere on the board
M1_IB: J9.G1; also elsewhere on the board
M1_IC: J9.J2; also elsewhere on the board
M1_PWMA: J9.H6; also elsewhere on the board
M1_PWMB: J9.K6; also elsewhere on the board
M1_PWMC: J9.J6; also elsewhere on the board
M2_BEMFA: J9.E3; also elsewhere on the board
M2_BEMFB: J9.D2; also elsewhere on the board
M2_BEMFC: J9.C2; also elsewhere on the board
M2_IA: J9.C1; also elsewhere on the board
M2_IB: J9.D1; also elsewhere on the board
M2_IC: J9.D3; also elsewhere on the board
M2_PWMA: J9.A6; also elsewhere on the board
M2_PWMB: J9.B6; also elsewhere on the board
M2_PWMC: J9.B4; also elsewhere on the board
M3_BEMFA: J9.K4; also elsewhere on the board
M3_BEMFB: J9.B5; also elsewhere on the board
M3_BEMFC: J9.H5; also elsewhere on the board
M3_IA: J9.K3; also elsewhere on the board
M3_IB: J9.K5; also elsewhere on the board
M3_IC: J9.H4; also elsewhere on the board
M3_PWMA: J9.A7; also elsewhere on the board
M3_PWMB: J9.J8; also elsewhere on the board
M3_PWMC: J9.B10; also elsewhere on the board
M4_BEMFA: J9.A4; also elsewhere on the board
M4_BEMFB: J9.K8; also elsewhere on the board
M4_BEMFC: J9.E2; also elsewhere on the board
M4_IA: J9.B3; also elsewhere on the board
M4_IB: J9.J7; also elsewhere on the board
M4_IC: J9.A2; also elsewhere on the board
M4_PWMA: J9.A10; also elsewhere on the board
M4_PWMB: J9.A9; also elsewhere on the board
M4_PWMC: J9.C9; also elsewhere on the board
M_TEMP1: J9.F1; also elsewhere on the board
M_TEMP2: J9.B2; also elsewhere on the board
M_TEMP3: J9.G3; also elsewhere on the board
M_TEMP4: J9.E1; also elsewhere on the board
unnamed: D2.2 (A), R23.2
SPI_MISO: J9.B8; also elsewhere on the board
SPI_MOSI: J9.C7; also elsewhere on the board
SPI_SCLK: J9.C8; also elsewhere on the board
SPI_nCSM1: J9.G2; also elsewhere on the board
SPI_nCSM2: J9.B7; also elsewhere on the board
SPI_nCSM3: J9.H7; also elsewhere on the board
SPI_nCSM4: J9.A8; also elsewhere on the board
SWCLK: J7.4, J9.J9
SWDIO: J7.2, J9.K10
SWO: J7.6, J9.E9
TDI: J7.8, J9.J10
VAA: J9.F5; also elsewhere on the board
VBAT_SNS: C27.1, J9.J5, R19.2, R21.1
nFAULTM1: J9.K2; also elsewhere on the board
nFAULTM2: J9.C6; also elsewhere on the board
nFAULTM3: J9.G10; also elsewhere on the board
nFAULTM4: J9.A5; also elsewhere on the board
nRST: J7.10, J9.C5

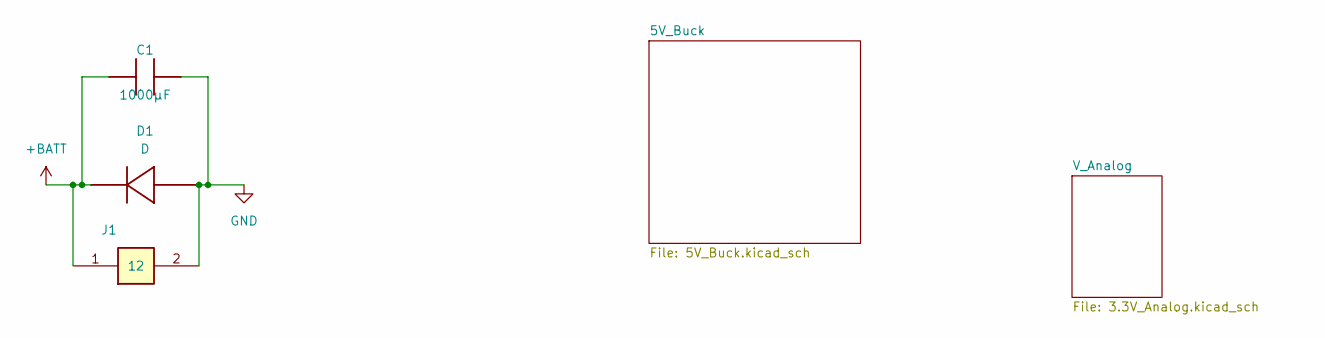
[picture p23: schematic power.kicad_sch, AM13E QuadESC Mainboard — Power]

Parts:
C1: 1000µF
D1: D; SMAJ26A
J1: WirePad_Battery_2P_5.0x9.0_DualSide

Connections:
+BATT: C1.1, D1.2, J1.1; also elsewhere on the board
GND: C1.2, D1.1, J1.2; also elsewhere on the board

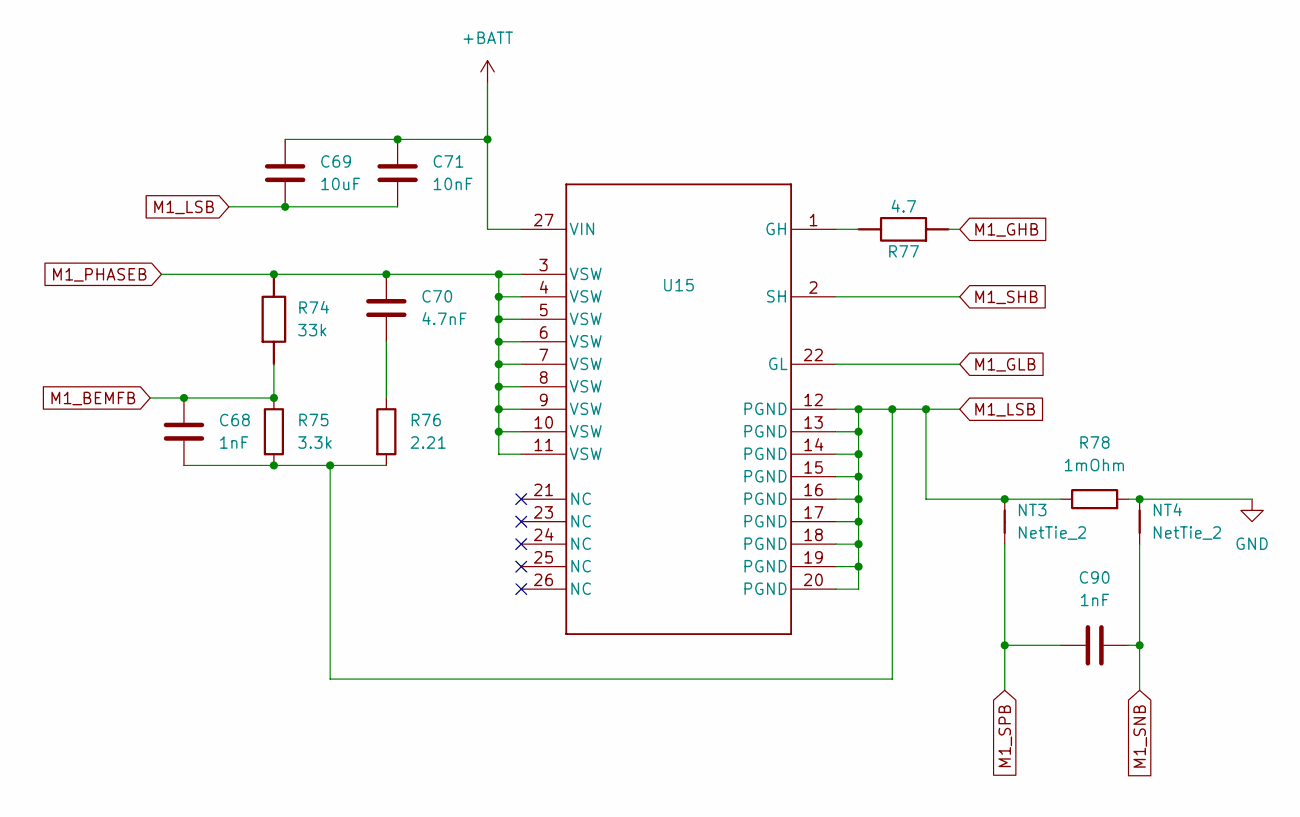
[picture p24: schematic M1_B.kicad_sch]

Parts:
C68, C90: 1nF; C_0201_0603Metric
C69: 10uF; C_1206_3216Metric
C70: 4.7nF; C_0402_1005Metric
C71: 10nF; C_0402_1005Metric
NT3, NT4: NetTie_2; NetTie-2_SMD_Pad0.2mm
R74: 33k; R_0402_1005Metric
R75: 3.3k; R_0201_0603Metric
R76: 2.21; R_0805_2012Metric
R77: 4.7; R_0402_1005Metric
R78: 1mOhm; RES_1L00x_BRN
U15: CSD88599Q5DC; DMM0022A

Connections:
+BATT: C69.1, C71.1, U15.27 (VIN); also elsewhere on the board
GND: NT4.2, R78.2; also elsewhere on the board
M1_BEMFB: C68.2, R74.1, R75.1; also elsewhere on the board
M1_GHB: R77.1; also elsewhere on the board
M1_GLB: U15.22 (GL); also elsewhere on the board
M1_LSB: C68.1, C69.2, C71.2, NT3.2, R75.2, R76.2, R78.1, U15.12 (PGND), U15.13 (PGND), U15.14 (PGND), U15.15 (PGND), U15.16 (PGND), U15.17 (PGND), U15.18 (PGND), U15.19 (PGND), U15.20 (PGND)
M1_PHASEB: C70.1, R74.2, U15.3 (VSW), U15.4 (VSW), U15.5 (VSW), U15.6 (VSW), U15.7 (VSW), U15.8 (VSW), U15.9 (VSW), U15.10 (VSW), U15.11 (VSW); also elsewhere on the board
M1_SHB: U15.2 (SH); also elsewhere on the board
M1_SNB: C90.2, NT4.1; also elsewhere on the board
M1_SPB: C90.1, NT3.1; also elsewhere on the board
unnamed: C70.2, R76.1
unnamed: R77.2, U15.1 (GH)

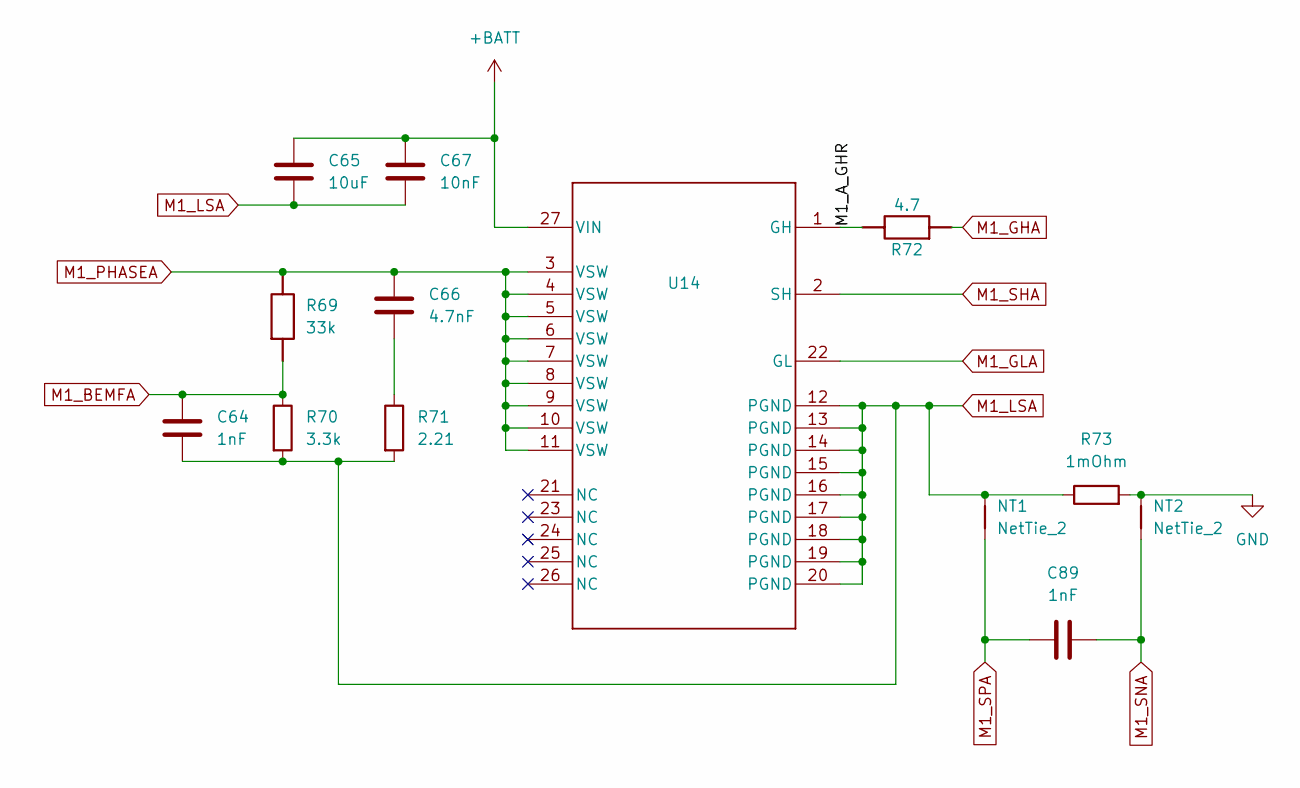
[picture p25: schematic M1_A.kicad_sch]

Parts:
C64, C89: 1nF; C_0201_0603Metric
C65: 10uF; C_1206_3216Metric
C66: 4.7nF; C_0402_1005Metric
C67: 10nF; C_0402_1005Metric
NT1, NT2: NetTie_2; NetTie-2_SMD_Pad0.2mm
R69: 33k; R_0402_1005Metric
R70: 3.3k; R_0201_0603Metric
R71: 2.21; R_0805_2012Metric
R72: 4.7; R_0402_1005Metric
R73: 1mOhm; RES_1L00x_BRN
U14: CSD88599Q5DC; DMM0022A

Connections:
+BATT: C65.1, C67.1, U14.27 (VIN); also elsewhere on the board
/M1/M1_A/M1_A_GHR: R72.2, U14.1 (GH)
GND: NT2.2, R73.2; also elsewhere on the board
M1_BEMFA: C64.2, R69.1, R70.1; also elsewhere on the board
M1_GHA: R72.1; also elsewhere on the board
M1_GLA: U14.22 (GL); also elsewhere on the board
M1_LSA: C64.1, C65.2, C67.2, NT1.2, R70.2, R71.2, R73.1, U14.12 (PGND), U14.13 (PGND), U14.14 (PGND), U14.15 (PGND), U14.16 (PGND), U14.17 (PGND), U14.18 (PGND), U14.19 (PGND), U14.20 (PGND)
M1_PHASEA: C66.1, R69.2, U14.3 (VSW), U14.4 (VSW), U14.5 (VSW), U14.6 (VSW), U14.7 (VSW), U14.8 (VSW), U14.9 (VSW), U14.10 (VSW), U14.11 (VSW); also elsewhere on the board
M1_SHA: U14.2 (SH); also elsewhere on the board
M1_SNA: C89.2, NT2.1; also elsewhere on the board
M1_SPA: C89.1, NT1.1; also elsewhere on the board
unnamed: C66.2, R71.1

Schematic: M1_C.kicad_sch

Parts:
C72, C91: 1nF; C_0201_0603Metric
C73: 10uF; C_1206_3216Metric
C74: 4.7nF; C_0402_1005Metric
C75: 10nF; C_0402_1005Metric
NT5, NT6: NetTie_2; NetTie-2_SMD_Pad0.2mm
R79: 33k; R_0402_1005Metric
R80: 3.3k; R_0201_0603Metric
R81: 2.21; R_0805_2012Metric
R82: 4.7; R_0402_1005Metric
R83: 1mOhm; RES_1L00x_BRN
U16: CSD88599Q5DC; DMM0022A

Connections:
+BATT: C73.1, C75.1, U16.27 (VIN); also elsewhere on the board
GND: NT6.2, R83.2; also elsewhere on the board
M1_BEMFC: C72.2, R79.1, R80.1; also elsewhere on the board
M1_GHC: R82.1; also elsewhere on the board
M1_GLC: U16.22 (GL); also elsewhere on the board
M1_LSC: C72.1, C73.2, C75.2, NT5.2, R80.2, R81.2, R83.1, U16.12 (PGND), U16.13 (PGND), U16.14 (PGND), U16.15 (PGND), U16.16 (PGND), U16.17 (PGND), U16.18 (PGND), U16.19 (PGND), U16.20 (PGND)
M1_PHASEC: C74.1, R79.2, U16.3 (VSW), U16.4 (VSW), U16.5 (VSW), U16.6 (VSW), U16.7 (VSW), U16.8 (VSW), U16.9 (VSW), U16.10 (VSW), U16.11 (VSW); also elsewhere on the board
M1_SHC: U16.2 (SH); also elsewhere on the board
M1_SNC: C91.2, NT6.1; also elsewhere on the board
M1_SPC: C91.1, NT5.1; also elsewhere on the board
unnamed: C74.2, R81.1
unnamed: R82.2, U16.1 (GH)

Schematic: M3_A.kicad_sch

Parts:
C40, C95: 1nF; C_0201_0603Metric
C41: 10uF; C_1206_3216Metric
C42: 4.7nF; C_0402_1005Metric
C43: 10nF; C_0402_1005Metric
NT13, NT14: NetTie_2; NetTie-2_SMD_Pad0.2mm
R39: 33k; R_0402_1005Metric
R40: 3.3k; R_0201_0603Metric
R41: 2.21; R_0805_2012Metric
R42: 4.7; R_0402_1005Metric
R43: 1mOhm; RES_1L00x_BRN
U8: CSD88599Q5DC; DMM0022A

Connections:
+BATT: C41.1, C43.1, U8.27 (VIN); also elsewhere on the board
GND: NT14.2, R43.2; also elsewhere on the board
M3_BEMFA: C40.2, R39.1, R40.1; also elsewhere on the board
M3_GHA: R42.1; also elsewhere on the board
M3_GLA: U8.22 (GL); also elsewhere on the board
M3_LSA: C40.1, C41.2, C43.2, NT13.2, R40.2, R41.2, R43.1, U8.12 (PGND), U8.13 (PGND), U8.14 (PGND), U8.15 (PGND), U8.16 (PGND), U8.17 (PGND), U8.18 (PGND), U8.19 (PGND), U8.20 (PGND)
M3_PHASEA: C42.1, R39.2, U8.3 (VSW), U8.4 (VSW), U8.5 (VSW), U8.6 (VSW), U8.7 (VSW), U8.8 (VSW), U8.9 (VSW), U8.10 (VSW), U8.11 (VSW); also elsewhere on the board
M3_SHA: U8.2 (SH); also elsewhere on the board
M3_SNA: C95.2, NT14.1; also elsewhere on the board
M3_SPA: C95.1, NT13.1; also elsewhere on the board
unnamed: C42.2, R41.1
unnamed: R42.2, U8.1 (GH)

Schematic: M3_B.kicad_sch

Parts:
C44, C96: 1nF; C_0201_0603Metric
C45: 10uF; C_1206_3216Metric
C46: 4.7nF; C_0402_1005Metric
C47: 10nF; C_0402_1005Metric
NT15, NT16: NetTie_2; NetTie-2_SMD_Pad0.2mm
R44: 33k; R_0402_1005Metric
R45: 3.3k; R_0201_0603Metric
R46: 2.21; R_0805_2012Metric
R47: 4.7; R_0402_1005Metric
R48: 1mOhm; RES_1L00x_BRN
U9: CSD88599Q5DC; DMM0022A

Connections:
+BATT: C45.1, C47.1, U9.27 (VIN); also elsewhere on the board
GND: NT16.2, R48.2; also elsewhere on the board
M3_BEMFB: C44.2, R44.1, R45.1; also elsewhere on the board
M3_GHB: R47.1; also elsewhere on the board
M3_GLB: U9.22 (GL); also elsewhere on the board
M3_LSB: C44.1, C45.2, C47.2, NT15.2, R45.2, R46.2, R48.1, U9.12 (PGND), U9.13 (PGND), U9.14 (PGND), U9.15 (PGND), U9.16 (PGND), U9.17 (PGND), U9.18 (PGND), U9.19 (PGND), U9.20 (PGND)
M3_PHASEB: C46.1, R44.2, U9.3 (VSW), U9.4 (VSW), U9.5 (VSW), U9.6 (VSW), U9.7 (VSW), U9.8 (VSW), U9.9 (VSW), U9.10 (VSW), U9.11 (VSW); also elsewhere on the board
M3_SHB: U9.2 (SH); also elsewhere on the board
M3_SNB: C96.2, NT16.1; also elsewhere on the board
M3_SPB: C96.1, NT15.1; also elsewhere on the board
unnamed: C46.2, R46.1
unnamed: R47.2, U9.1 (GH)

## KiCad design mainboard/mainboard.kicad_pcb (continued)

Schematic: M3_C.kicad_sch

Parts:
C48, C97: 1nF; C_0201_0603Metric
C49: 10uF; C_1206_3216Metric
C50: 4.7nF; C_0402_1005Metric
C51: 10nF; C_0402_1005Metric
NT17, NT18: NetTie_2; NetTie-2_SMD_Pad0.2mm
R49: 33k; R_0402_1005Metric
R50: 3.3k; R_0201_0603Metric
R51: 2.21; R_0805_2012Metric
R52: 4.7; R_0402_1005Metric
R53: 1mOhm; RES_1L00x_BRN
U10: CSD88599Q5DC; DMM0022A

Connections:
+BATT: C49.1, C51.1, U10.27 (VIN); also elsewhere on the board
GND: NT18.2, R53.2; also elsewhere on the board
M3_BEMFC: C48.2, R49.1, R50.1; also elsewhere on the board
M3_GHC: R52.1; also elsewhere on the board
M3_GLC: U10.22 (GL); also elsewhere on the board
M3_LSC: C48.1, C49.2, C51.2, NT17.2, R50.2, R51.2, R53.1, U10.12 (PGND), U10.13 (PGND), U10.14 (PGND), U10.15 (PGND), U10.16 (PGND), U10.17 (PGND), U10.18 (PGND), U10.19 (PGND), U10.20 (PGND)
M3_PHASEC: C50.1, R49.2, U10.3 (VSW), U10.4 (VSW), U10.5 (VSW), U10.6 (VSW), U10.7 (VSW), U10.8 (VSW), U10.9 (VSW), U10.10 (VSW), U10.11 (VSW); also elsewhere on the board
M3_SHC: U10.2 (SH); also elsewhere on the board
M3_SNC: C97.2, NT18.1; also elsewhere on the board
M3_SPC: C97.1, NT17.1; also elsewhere on the board
unnamed: C50.2, R51.1
unnamed: R52.2, U10.1 (GH)

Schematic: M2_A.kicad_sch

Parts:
C52, C92: 1nF; C_0201_0603Metric
C53: 10uF; C_1206_3216Metric
C54: 4.7nF; C_0402_1005Metric
C55: 10nF; C_0402_1005Metric
NT7, NT8: NetTie_2; NetTie-2_SMD_Pad0.2mm
R54: 33k; R_0402_1005Metric
R55: 3.3k; R_0201_0603Metric
R56: 2.21; R_0805_2012Metric
R57: 4.7; R_0402_1005Metric
R58: 1mOhm; RES_1L00x_BRN
U11: CSD88599Q5DC; DMM0022A

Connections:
+BATT: C53.1, C55.1, U11.27 (VIN); also elsewhere on the board
GND: NT8.2, R58.2; also elsewhere on the board
M2_BEMFA: C52.2, R54.1, R55.1; also elsewhere on the board
M2_GHA: R57.1; also elsewhere on the board
M2_GLA: U11.22 (GL); also elsewhere on the board
M2_LSA: C52.1, C53.2, C55.2, NT7.2, R55.2, R56.2, R58.1, U11.12 (PGND), U11.13 (PGND), U11.14 (PGND), U11.15 (PGND), U11.16 (PGND), U11.17 (PGND), U11.18 (PGND), U11.19 (PGND), U11.20 (PGND)
M2_PHASEA: C54.1, R54.2, U11.3 (VSW), U11.4 (VSW), U11.5 (VSW), U11.6 (VSW), U11.7 (VSW), U11.8 (VSW), U11.9 (VSW), U11.10 (VSW), U11.11 (VSW); also elsewhere on the board
M2_SHA: U11.2 (SH); also elsewhere on the board
M2_SNA: C92.2, NT8.1; also elsewhere on the board
M2_SPA: C92.1, NT7.1; also elsewhere on the board
unnamed: C54.2, R56.1
unnamed: R57.2, U11.1 (GH)

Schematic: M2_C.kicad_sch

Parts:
C60, C94: 1nF; C_0201_0603Metric
C61: 10uF; C_1206_3216Metric
C62: 4.7nF; C_0402_1005Metric
C63: 10nF; C_0402_1005Metric
NT11, NT12: NetTie_2; NetTie-2_SMD_Pad0.2mm
R64: 33k; R_0402_1005Metric
R65: 3.3k; R_0201_0603Metric
R66: 2.21; R_0805_2012Metric
R67: 4.7; R_0402_1005Metric
R68: 1mOhm; RES_1L00x_BRN
U13: CSD88599Q5DC; DMM0022A

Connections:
+BATT: C61.1, C63.1, U13.27 (VIN); also elsewhere on the board
GND: NT12.2, R68.2; also elsewhere on the board
M2_BEMFC: C60.2, R64.1, R65.1; also elsewhere on the board
M2_GHC: R67.1; also elsewhere on the board
M2_GLC: U13.22 (GL); also elsewhere on the board
M2_LSC: C60.1, C61.2, C63.2, NT11.2, R65.2, R66.2, R68.1, U13.12 (PGND), U13.13 (PGND), U13.14 (PGND), U13.15 (PGND), U13.16 (PGND), U13.17 (PGND), U13.18 (PGND), U13.19 (PGND), U13.20 (PGND)
M2_PHASEC: C62.1, R64.2, U13.3 (VSW), U13.4 (VSW), U13.5 (VSW), U13.6 (VSW), U13.7 (VSW), U13.8 (VSW), U13.9 (VSW), U13.10 (VSW), U13.11 (VSW); also elsewhere on the board
M2_SHC: U13.2 (SH); also elsewhere on the board
M2_SNC: C94.2, NT12.1; also elsewhere on the board
M2_SPC: C94.1, NT11.1; also elsewhere on the board
unnamed: C62.2, R66.1
unnamed: R67.2, U13.1 (GH)

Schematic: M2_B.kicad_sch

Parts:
C56, C93: 1nF; C_0201_0603Metric
C57: 10uF; C_1206_3216Metric
C58: 4.7nF; C_0402_1005Metric
C59: 10nF; C_0402_1005Metric
NT9, NT10: NetTie_2; NetTie-2_SMD_Pad0.2mm
R59: 33k; R_0402_1005Metric
R60: 3.3k; R_0201_0603Metric
R61: 2.21; R_0805_2012Metric
R62: 4.7; R_0402_1005Metric
R63: 1mOhm; RES_1L00x_BRN
U12: CSD88599Q5DC; DMM0022A

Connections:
+BATT: C57.1, C59.1, U12.27 (VIN); also elsewhere on the board
GND: NT10.2, R63.2; also elsewhere on the board
M2_BEMFB: C56.2, R59.1, R60.1; also elsewhere on the board
M2_GHB: R62.1; also elsewhere on the board
M2_GLB: U12.22 (GL); also elsewhere on the board
M2_LSB: C56.1, C57.2, C59.2, NT9.2, R60.2, R61.2, R63.1, U12.12 (PGND), U12.13 (PGND), U12.14 (PGND), U12.15 (PGND), U12.16 (PGND), U12.17 (PGND), U12.18 (PGND), U12.19 (PGND), U12.20 (PGND)
M2_PHASEB: C58.1, R59.2, U12.3 (VSW), U12.4 (VSW), U12.5 (VSW), U12.6 (VSW), U12.7 (VSW), U12.8 (VSW), U12.9 (VSW), U12.10 (VSW), U12.11 (VSW); also elsewhere on the board
M2_SHB: U12.2 (SH); also elsewhere on the board
M2_SNB: C93.2, NT10.1; also elsewhere on the board
M2_SPB: C93.1, NT9.1; also elsewhere on the board
unnamed: C58.2, R61.1
unnamed: R62.2, U12.1 (GH)

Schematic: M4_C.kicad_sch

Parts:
C36, C100: 1nF; C_0201_0603Metric
C37: 10uF; C_1206_3216Metric
C38: 4.7nF; C_0402_1005Metric
C39: 10nF; C_0402_1005Metric
NT23, NT24: NetTie_2; NetTie-2_SMD_Pad0.2mm
R34: 33k; R_0402_1005Metric
R35: 3.3k; R_0201_0603Metric
R36: 2.21; R_0805_2012Metric
R37: 4.7; R_0402_1005Metric
R38: 1mOhm; RES_1L00x_BRN
U7: CSD88599Q5DC; DMM0022A

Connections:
+BATT: C37.1, C39.1, U7.27 (VIN); also elsewhere on the board
GND: NT24.2, R38.2; also elsewhere on the board
M4_BEMFC: C36.2, R34.1, R35.1; also elsewhere on the board
M4_GHC: R37.1; also elsewhere on the board
M4_GLC: U7.22 (GL); also elsewhere on the board
M4_LSC: C36.1, C37.2, C39.2, NT23.2, R35.2, R36.2, R38.1, U7.12 (PGND), U7.13 (PGND), U7.14 (PGND), U7.15 (PGND), U7.16 (PGND), U7.17 (PGND), U7.18 (PGND), U7.19 (PGND), U7.20 (PGND)
M4_PHASEC: C38.1, R34.2, U7.3 (VSW), U7.4 (VSW), U7.5 (VSW), U7.6 (VSW), U7.7 (VSW), U7.8 (VSW), U7.9 (VSW), U7.10 (VSW), U7.11 (VSW); also elsewhere on the board
M4_SHC: U7.2 (SH); also elsewhere on the board
M4_SNC: C100.2, NT24.1; also elsewhere on the board
M4_SPC: C100.1, NT23.1; also elsewhere on the board
unnamed: C38.2, R36.1
unnamed: R37.2, U7.1 (GH)

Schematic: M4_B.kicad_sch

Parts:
C32, C99: 1nF; C_0201_0603Metric
C33: 10uF; C_1206_3216Metric
C34: 4.7nF; C_0402_1005Metric
C35: 10nF; C_0402_1005Metric
NT21, NT22: NetTie_2; NetTie-2_SMD_Pad0.2mm
R29: 33k; R_0402_1005Metric
R30: 3.3k; R_0201_0603Metric
R31: 2.21; R_0805_2012Metric
R32: 4.7; R_0402_1005Metric
R33: 1mOhm; RES_1L00x_BRN
U6: CSD88599Q5DC; DMM0022A

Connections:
+BATT: C33.1, C35.1, U6.27 (VIN); also elsewhere on the board
GND: NT22.2, R33.2; also elsewhere on the board
M4_BEMFB: C32.2, R29.1, R30.1; also elsewhere on the board
M4_GHB: R32.1; also elsewhere on the board
M4_GLB: U6.22 (GL); also elsewhere on the board
M4_LSB: C32.1, C33.2, C35.2, NT21.2, R30.2, R31.2, R33.1, U6.12 (PGND), U6.13 (PGND), U6.14 (PGND), U6.15 (PGND), U6.16 (PGND), U6.17 (PGND), U6.18 (PGND), U6.19 (PGND), U6.20 (PGND)
M4_PHASEB: C34.1, R29.2, U6.3 (VSW), U6.4 (VSW), U6.5 (VSW), U6.6 (VSW), U6.7 (VSW), U6.8 (VSW), U6.9 (VSW), U6.10 (VSW), U6.11 (VSW); also elsewhere on the board
M4_SHB: U6.2 (SH); also elsewhere on the board
M4_SNB: C99.2, NT22.1; also elsewhere on the board
M4_SPB: C99.1, NT21.1; also elsewhere on the board
unnamed: C34.2, R31.1
unnamed: R32.2, U6.1 (GH)

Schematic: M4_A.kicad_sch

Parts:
C28, C98: 1nF; C_0201_0603Metric
C29: 10uF; C_1206_3216Metric
C30: 4.7nF; C_0402_1005Metric
C31: 10nF; C_0402_1005Metric
NT19, NT20: NetTie_2; NetTie-2_SMD_Pad0.2mm
R24: 33k; R_0402_1005Metric
R25: 3.3k; R_0201_0603Metric
R26: 2.21; R_0805_2012Metric
R27: 4.7; R_0402_1005Metric
R28: 1mOhm; RES_1L00x_BRN
U5: CSD88599Q5DC; DMM0022A

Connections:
+BATT: C29.1, C31.1, U5.27 (VIN); also elsewhere on the board
GND: NT20.2, R28.2; also elsewhere on the board
M4_BEMFA: C28.2, R24.1, R25.1; also elsewhere on the board
M4_GHA: R27.1; also elsewhere on the board
M4_GLA: U5.22 (GL); also elsewhere on the board
M4_LSA: C28.1, C29.2, C31.2, NT19.2, R25.2, R26.2, R28.1, U5.12 (PGND), U5.13 (PGND), U5.14 (PGND), U5.15 (PGND), U5.16 (PGND), U5.17 (PGND), U5.18 (PGND), U5.19 (PGND), U5.20 (PGND)
M4_PHASEA: C30.1, R24.2, U5.3 (VSW), U5.4 (VSW), U5.5 (VSW), U5.6 (VSW), U5.7 (VSW), U5.8 (VSW), U5.9 (VSW), U5.10 (VSW), U5.11 (VSW); also elsewhere on the board
M4_SHA: U5.2 (SH); also elsewhere on the board
M4_SNA: C98.2, NT20.1; also elsewhere on the board
M4_SPA: C98.1, NT19.1; also elsewhere on the board
unnamed: C30.2, R26.1
unnamed: R27.2, U5.1 (GH)

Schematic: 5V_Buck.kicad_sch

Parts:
C76, C77: 4.7uF; C_0805_2012Metric
C78: .1uF; C_0201_0603Metric
C79: 6.8nF; C_0201_0603Metric
C80: 39pF; C_0201_0603Metric
C81, C88: 22uF; C_1206_3216Metric
C82: 1uF; C_0402_1005Metric
D3: D; PMEG4030AEXEQX
L1: 10uH; INDPM4441X200N
R84: 162k; R_0201_0603Metric
R85: 10.5k; R_0201_0603Metric
R86: 2k; R_0201_0603Metric
R87: 13k; R_0201_0603Metric
U17: TPS54360BDDAR; U_DDA_TEX

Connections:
+BATT: C76.1, C77.1, U17.2 (VIN); also elsewhere on the board
BUCK_OUT: C81.1, C82.1, C88.1, L1.2, R85.2; also elsewhere on the board
GND: C76.2, C77.2, C79.2, C80.2, C81.2, C82.2, C88.2, D3.2 (A), R84.2, R86.2, U17.7 (GND), U17.9 (EPAD); also elsewhere on the board
unnamed: C79.1, R87.1
unnamed: C78.2, D3.1 (K), L1.1, U17.8 (SW)
unnamed: C78.1, U17.1 (BOOT)
unnamed: C80.1, R87.2, U17.6 (COMP)
unnamed: R85.1, R86.1, U17.5 (FB)
unnamed: R84.1, U17.4 (RT/CLK)

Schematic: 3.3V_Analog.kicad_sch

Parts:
C83: 10uF; C_0805_2012Metric
C84: .1uF; C_0201_0603Metric
C85: 1uF; C_0402_1005Metric
C86, C87: 22uF; C_1206_3216Metric
R88, R89, R90: 0; R_0201_0603Metric
U18: TPS7A4701RGWR; RGW0020A-IPC_A

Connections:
BUCK_OUT: C83.1, C84.1, U18.13 (EN), U18.15 (IN), U18.16 (IN); also elsewhere on the board
GND: C83.2, C84.2, C85.2, C86.2, C87.2, R88.2, R89.2, R90.2, U18.7 (GND), U18.21 (Thermal_Pad); also elsewhere on the board
unnamed: R88.1, U18.12 (0P1V)
unnamed: R89.1, U18.11 (0P2V)
unnamed: R90.1, U18.8 (1P6V)
unnamed: C85.1, U18.14 (NR)
VAA: C86.1, C87.1, U18.1 (OUT), U18.3 (SENSE_FB), U18.20 (OUT); also elsewhere on the board

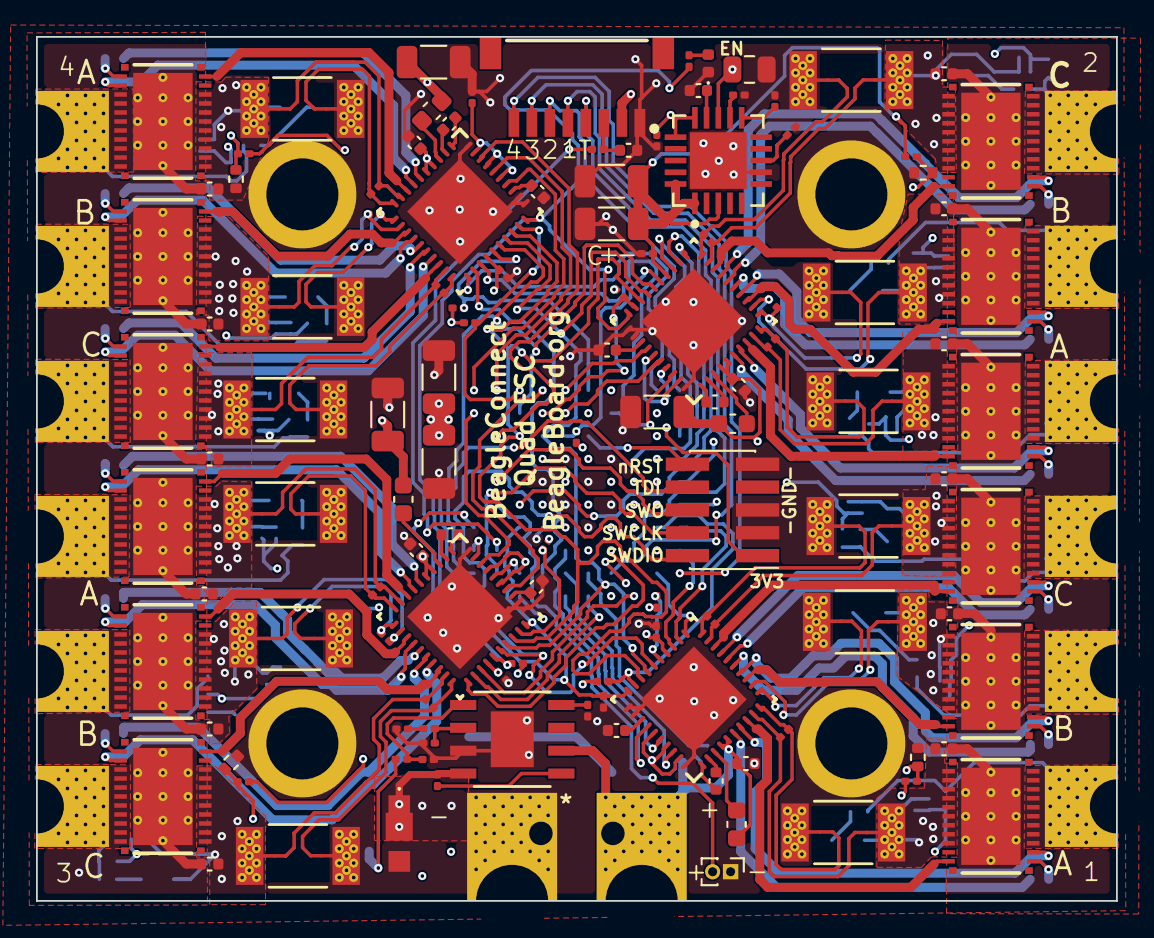
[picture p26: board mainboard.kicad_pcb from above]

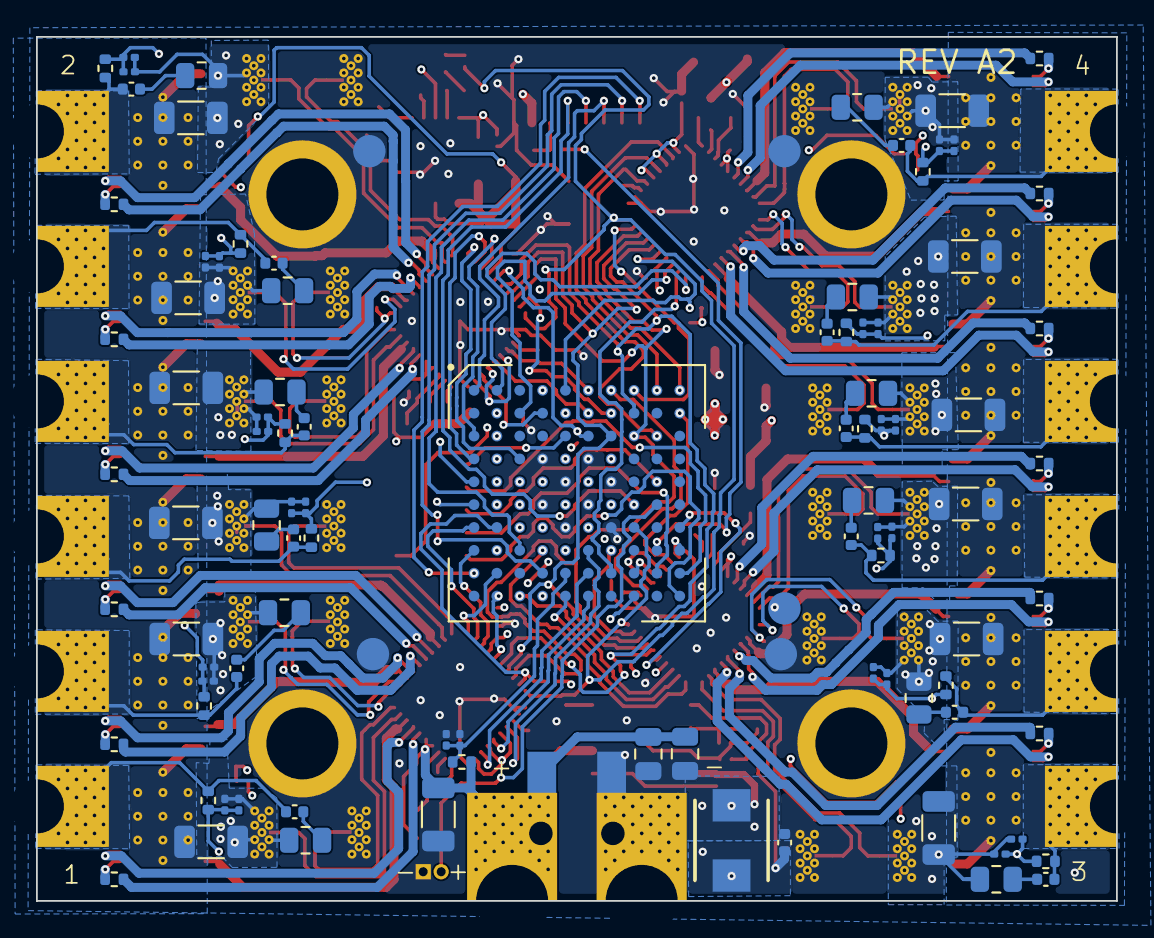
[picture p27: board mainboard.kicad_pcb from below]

Board: 6 copper layers, 60.0 x 48.0 mm, 247 parts (95 on the bottom side), 207 nets.

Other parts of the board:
MH1, MH2, MH3, MH4: MountingHole_M3_3.0mmDrill_6.0mmPad

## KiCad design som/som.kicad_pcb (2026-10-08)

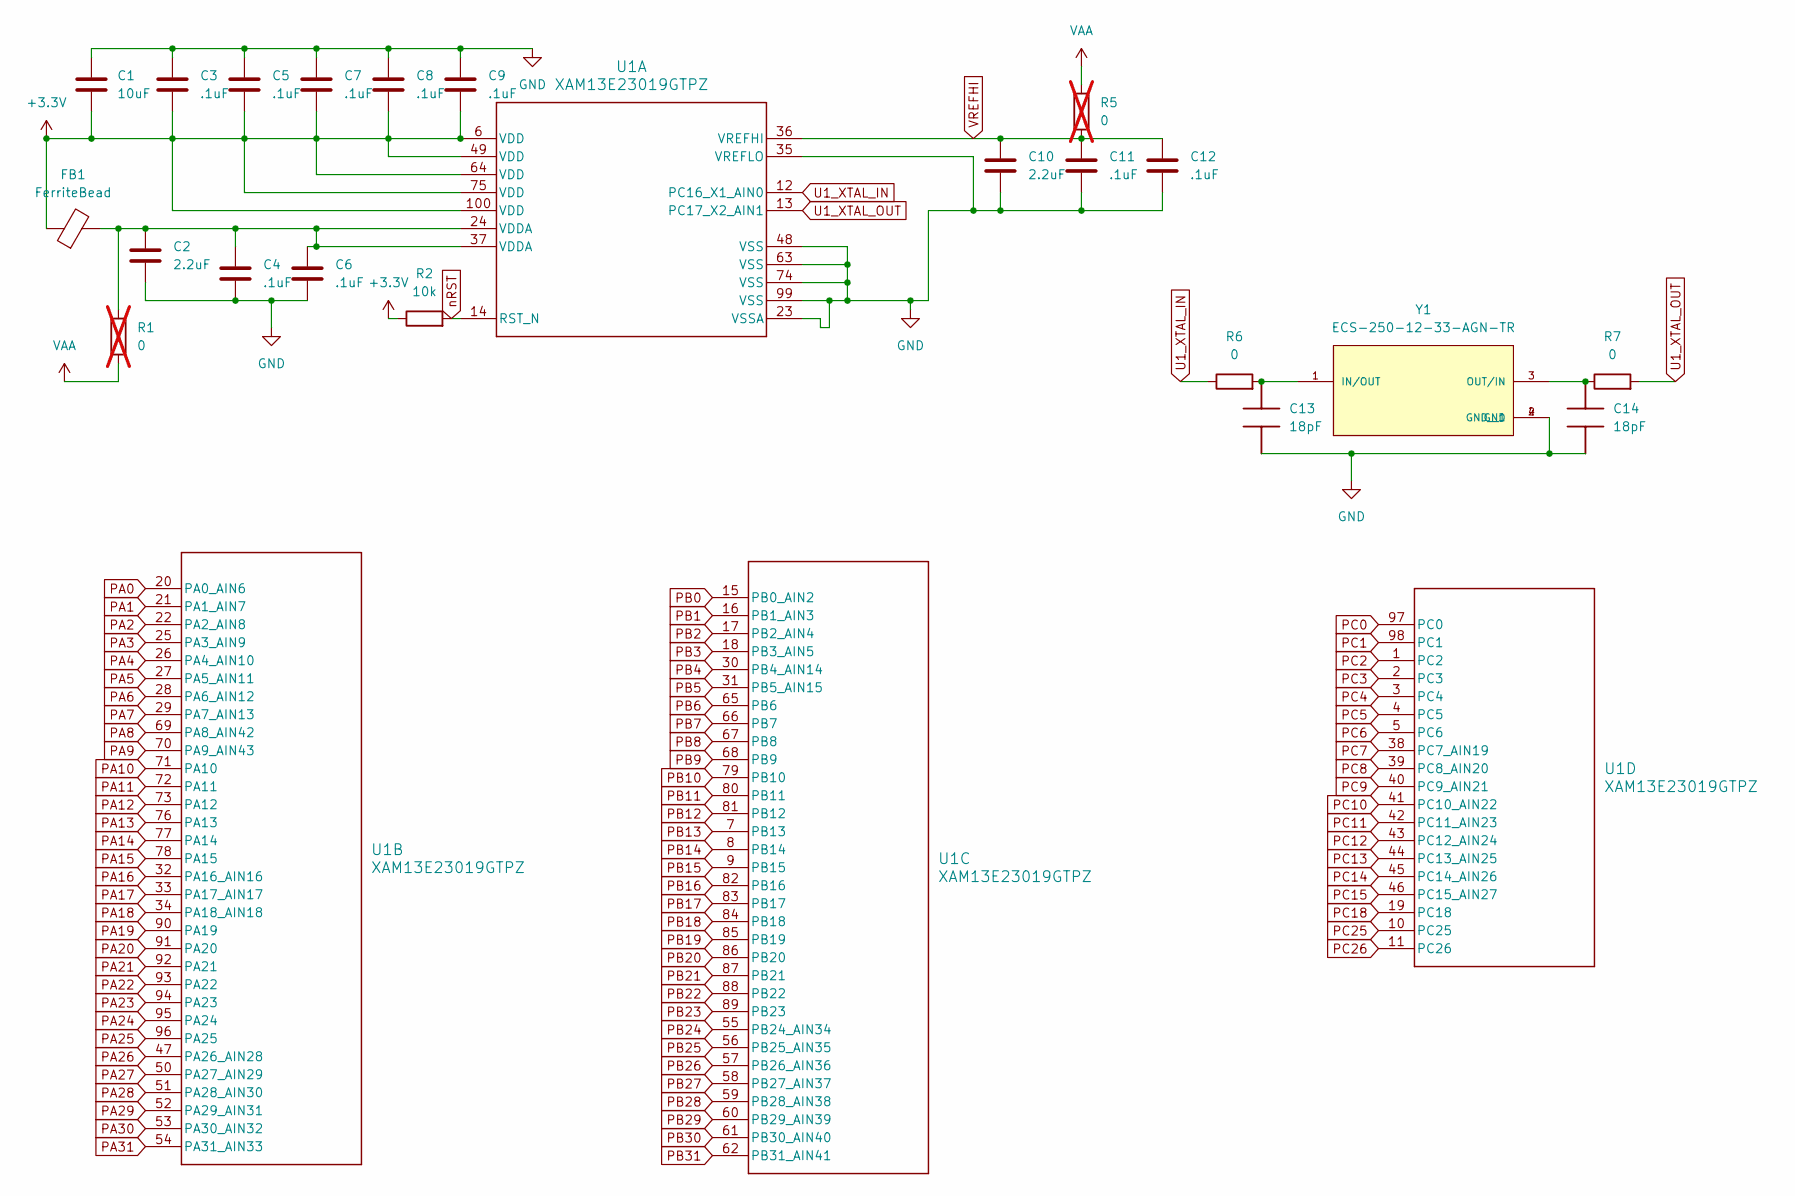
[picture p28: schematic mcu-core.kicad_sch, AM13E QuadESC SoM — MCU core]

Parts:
C1: 10uF; C_0603_1608Metric
C2, C10: 2.2uF; C_0402_1005Metric
C3, C4, C5, C6, C7, C8, C9, C11, C12: .1uF; C_0201_0603Metric
C13, C14: 18pF; C_0402_1005Metric
FB1: FerriteBead; L_0603_1608Metric
R1, R5: 0; R_0201_0603Metric; not fitted
R2: 10k; R_0201_0603Metric
R6, R7: 0; R_0201_0603Metric
U1: XAM13E23019GTPZ; PZ0100A-MFG
Y1: ECS-250-12-33-AGN-TR; XTAL_ECS-250-12-33-AGN-TR

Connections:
+3.3V: C1.2, C3.1, C5.1, C7.1, C8.1, C9.1, FB1.1, R2.1, U1.6 (VDD), U1.49 (VDD), U1.64 (VDD), U1.75 (VDD), U1.100 (VDD); also elsewhere on the board
AN: U1.51 (PA28_AIN30); also elsewhere on the board
BSL_I2C_SCL: U1.94 (PA23); also elsewhere on the board
BSL_I2C_SDA: U1.93 (PA22); also elsewhere on the board
BSL_INVOKE: U1.28 (PA6_AIN12); also elsewhere on the board
BSL_UART_RX: U1.21 (PA1_AIN7); also elsewhere on the board
BSL_UART_TX: U1.20 (PA0_AIN6); also elsewhere on the board
CAN_RX: U1.72 (PA11); also elsewhere on the board
CAN_TERM: U1.97 (PC0); also elsewhere on the board
CAN_TX: U1.73 (PA12); also elsewhere on the board
GND: C1.1, C2.2, C3.2, C4.1, C5.2, C6.1, C7.2, C8.2, C9.2, C10.2, C11.1, C12.1, C13.1, C14.1, U1.23 (VSSA), U1.35 (VREFLO), U1.48 (VSS), U1.63 (VSS), U1.74 (VSS), U1.99 (VSS), Y1.2 (GND), Y1.4 (GND__1); also elsewhere on the board
INT: U1.17 (PB2_AIN4); also elsewhere on the board
unnamed: C2.1, C4.2, C6.2, FB1.2, R1.1, U1.24 (VDDA), U1.37 (VDDA)
unnamed: C13.2, R6.2, Y1.1 (IN/OUT)
unnamed: C14.2, R7.1, Y1.3 (OUT/IN)
PA2: U1.22 (PA2_AIN8); also elsewhere on the board
PA3: U1.25 (PA3_AIN9); also elsewhere on the board
PA4: U1.26 (PA4_AIN10); also elsewhere on the board
PA5: U1.27 (PA5_AIN11); also elsewhere on the board
PA7: U1.29 (PA7_AIN13); also elsewhere on the board
PA8: U1.69 (PA8_AIN42); also elsewhere on the board
PA9: U1.70 (PA9_AIN43); also elsewhere on the board
PA10: U1.71 (PA10); also elsewhere on the board
PA13: U1.76 (PA13); also elsewhere on the board
PA14: U1.77 (PA14); also elsewhere on the board
PA15: U1.78 (PA15); also elsewhere on the board
PA16: U1.32 (PA16_AIN16); also elsewhere on the board
PA17: U1.33 (PA17_AIN17); also elsewhere on the board
PA18: U1.34 (PA18_AIN18); also elsewhere on the board
PA19: U1.90 (PA19); also elsewhere on the board
PA20: U1.91 (PA20); also elsewhere on the board
PA21: U1.92 (PA21); also elsewhere on the board
PA24: U1.95 (PA24); also elsewhere on the board
PA25: U1.96 (PA25); also elsewhere on the board
PA26: U1.47 (PA26_AIN28); also elsewhere on the board
PA27: U1.50 (PA27_AIN29); also elsewhere on the board
PA29: U1.52 (PA29_AIN31); also elsewhere on the board
PA30: U1.53 (PA30_AIN32); also elsewhere on the board
PA31: U1.54 (PA31_AIN33); also elsewhere on the board
PB0: U1.15 (PB0_AIN2); also elsewhere on the board
PB1: U1.16 (PB1_AIN3); also elsewhere on the board
PB3: U1.18 (PB3_AIN5); also elsewhere on the board
PB4: U1.30 (PB4_AIN14); also elsewhere on the board
PB5: U1.31 (PB5_AIN15); also elsewhere on the board
PB6: U1.65 (PB6); also elsewhere on the board
PB7: U1.66 (PB7); also elsewhere on the board
PB8: U1.67 (PB8); also elsewhere on the board
PB9: U1.68 (PB9); also elsewhere on the board
PB10: U1.79 (PB10); also elsewhere on the board
PB11: U1.80 (PB11); also elsewhere on the board
PB12: U1.81 (PB12); also elsewhere on the board
PB13: U1.7 (PB13); also elsewhere on the board
PB14: U1.8 (PB14); also elsewhere on the board
PB15: U1.9 (PB15); also elsewhere on the board
PB16: U1.82 (PB16); also elsewhere on the board
PB17: U1.83 (PB17); also elsewhere on the board
PB18: U1.84 (PB18); also elsewhere on the board
PB19: U1.85 (PB19); also elsewhere on the board
PB20: U1.86 (PB20); also elsewhere on the board
PB21: U1.87 (PB21); also elsewhere on the board
PB22: U1.88 (PB22); also elsewhere on the board
PB23: U1.89 (PB23); also elsewhere on the board
PB24: U1.55 (PB24_AIN34); also elsewhere on the board
PB25: U1.56 (PB25_AIN35); also elsewhere on the board
PB26: U1.57 (PB26_AIN36); also elsewhere on the board
PB27: U1.58 (PB27_AIN37); also elsewhere on the board
PB28: U1.59 (PB28_AIN38); also elsewhere on the board
PB29: U1.60 (PB29_AIN39); also elsewhere on the board
PB30: U1.61 (PB30_AIN40); also elsewhere on the board
PB31: U1.62 (PB31_AIN41); also elsewhere on the board
PC1: U1.98 (PC1); also elsewhere on the board
PC2: U1.1 (PC2); also elsewhere on the board
PC3: U1.2 (PC3); also elsewhere on the board
PC4: U1.3 (PC4); also elsewhere on the board
PC5: U1.4 (PC5); also elsewhere on the board
PC6: U1.5 (PC6); also elsewhere on the board
PC7: U1.38 (PC7_AIN19); also elsewhere on the board
PC8: U1.39 (PC8_AIN20); also elsewhere on the board
PC9: U1.40 (PC9_AIN21); also elsewhere on the board
PC10: U1.41 (PC10_AIN22); also elsewhere on the board
PC11: U1.42 (PC11_AIN23); also elsewhere on the board
PC12: U1.43 (PC12_AIN24); also elsewhere on the board
PC13: U1.44 (PC13_AIN25); also elsewhere on the board
PC14: U1.45 (PC14_AIN26); also elsewhere on the board
PC15: U1.46 (PC15_AIN27); also elsewhere on the board
PC18: U1.19 (PC18); also elsewhere on the board
PC25: U1.10 (PC25); also elsewhere on the board
PC26: U1.11 (PC26); also elsewhere on the board
U1_XTAL_IN: R6.1, U1.12 (PC16_X1_AIN0)
U1_XTAL_OUT: R7.2, U1.13 (PC17_X2_AIN1)
VAA: R1.2, R5.1; also elsewhere on the board
VREFHI: C10.1, C11.2, C12.2, R5.2, U1.36 (VREFHI)
nRST: R2.2, U1.14 (RST_N); also elsewhere on the board

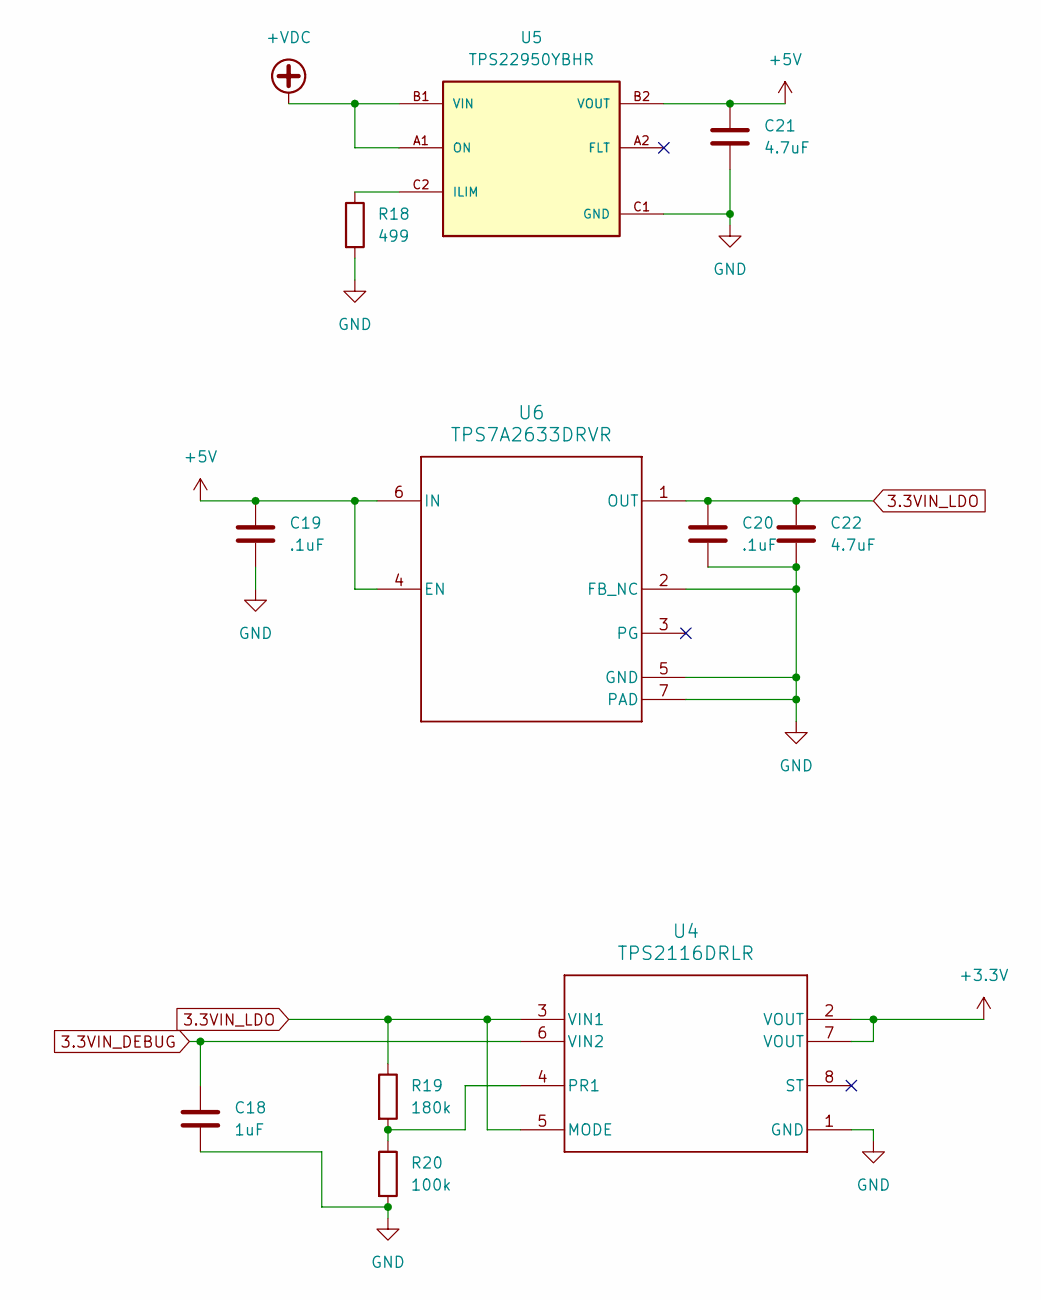
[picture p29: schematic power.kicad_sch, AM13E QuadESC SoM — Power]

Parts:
C18: 1uF; C_0402_1005Metric
C19, C20: .1uF; C_0201_0603Metric
C21, C22: 4.7uF; C_0402_1005Metric
R18: 499; R_0201_0603Metric
R19: 180k; R_0201_0603Metric
R20: 100k; R_0201_0603Metric
U4: TPS2116DRLR; DRL0008A-MFG
U5: TPS22950YBHR; IC_TPS22950YBHR; PARTREV December 2020
U6: TPS7A2633DRVR; DRV0006A

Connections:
3.3VIN_DEBUG: C18.1, U4.6 (VIN2); also elsewhere on the board
3.3VIN_LDO: C20.1, C22.1, R19.1, U4.3 (VIN1), U4.5 (MODE), U6.1 (OUT)
+3.3V: U4.2 (VOUT), U4.7 (VOUT); also elsewhere on the board
+5V: C19.1, C21.1, U5.B2 (VOUT), U6.4 (EN), U6.6 (IN); also elsewhere on the board
+VDC: U5.A1 (ON), U5.B1 (VIN); also elsewhere on the board
GND: C18.2, C19.2, C20.2, C21.2, C22.2, R18.2, R20.2, U4.1 (GND), U5.C1 (GND), U6.2 (FB_NC), U6.5 (GND), U6.7 (PAD); also elsewhere on the board
unnamed: R19.2, R20.1, U4.4 (PR1)
unnamed: R18.1, U5.C2 (ILIM)


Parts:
C15: 10uF; C_0603_1608Metric
C16, C17: .1uF; C_0201_0603Metric
CR1: ESD2CAN24DBZRQ1; SOT-23_DBZ_TEX
L1: ACT1210-101-2P-TL00; IND_01-2P-TL00_TDK
R8, R9: 0; R_0201_0603Metric; not fitted
R10: 120; R_1206_3216Metric
U2: TCAN844DRBRQ1; DRB0008J-MFG
U3: TS5A3166YZPR; YZP5

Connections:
+3.3V: C17.1, U2.5 (VIO); also elsewhere on the board
+5V: C15.1, C16.1, U2.3 (VCC), U3.A2; also elsewhere on the board
/can-transceiver/SW_NO: R10.2, U3.A1
CANH: CR1.1, L1.4, R8.2, R10.1; also elsewhere on the board
CANL: CR1.2, L1.3, R9.1, U3.B1; also elsewhere on the board
CAN_RX: U2.4 (RXD); also elsewhere on the board
CAN_TERM: U3.C2; also elsewhere on the board
CAN_TX: U2.1 (TXD); also elsewhere on the board
GND: C15.2, C16.2, C17.2, CR1.3, U2.2 (GND), U2.8 (STB), U2.9 (Thermal_Pad), U3.C1; also elsewhere on the board
unnamed: L1.1, R8.1, U2.7 (CANH)
unnamed: L1.2, R9.2, U2.6 (CANL)


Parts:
D1, D2: LED; LED_0402_1005Metric
J1: LGA-100_10x10_14.0x14.0mm
J2: ZEPTO_DEBUG; PinHeader_1x08_P2.54mm_Vertical; not fitted
J3: MikroBUS L; not fitted
J4: Qwiic; CONN_SM04B-SRSS-TB_JST
J5: Drone_CAN; JST_SM04B-GHS-TB
J6: MikroBUS R; not fitted
R11, R12: 2.2k; R_0201_0603Metric
R13: 1.5k; R_0201_0603Metric
R14, R17, R21: 10k; R_0201_0603Metric
R15, R16: 4.7k; R_0201_0603Metric

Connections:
3.3VIN_DEBUG: J2.1; also elsewhere on the board
+3.3V: J4.2, J6.11, R11.1, R12.1, R13.1, R14.1, R15.1, R16.1, R21.1; also elsewhere on the board
+5V: J3.11, J5.1, J6.4; also elsewhere on the board
+VDC: J1.D5, J1.D7, J1.E4, J1.E6, J1.F7, J1.G4, J1.G6; also elsewhere on the board
AN: J1.K1, J6.5; also elsewhere on the board
BSL_I2C_SCL: J1.C10, J3.9, J4.4, R16.2; also elsewhere on the board
BSL_I2C_SDA: J1.D9, J3.10, J4.3, R15.2; also elsewhere on the board
BSL_INVOKE: J1.B1, J2.8, R17.2; also elsewhere on the board
BSL_UART_RX: J1.C3, J2.6; also elsewhere on the board
BSL_UART_TX: J1.A3, J2.4; also elsewhere on the board
CANH: J5.2, J6.3; also elsewhere on the board
CANL: J5.3, J6.2; also elsewhere on the board
CAN_RX: J1.K9; also elsewhere on the board
CAN_TERM: J1.B9, R21.2; also elsewhere on the board
CAN_TX: J1.H8; also elsewhere on the board
GND: D2.1 (K), J1.D4, J1.D6, J1.E5, J1.E7, J1.F4, J1.F6, J1.G5, J1.G7, J2.5, J3.1, J3.12, J4.1, J5.4, J6.1, J6.12, R17.1; also elsewhere on the board
INT: J1.C4, J3.6; also elsewhere on the board
unnamed: D1.2 (A), R12.2
unnamed: D2.2 (A), R11.2
PA2: J1.A2; also elsewhere on the board
PA3: J1.B3; also elsewhere on the board
PA4: J1.A1; also elsewhere on the board
PA5: J1.B2; also elsewhere on the board
PA7: J1.D3; also elsewhere on the board
PA8: J1.J7; also elsewhere on the board
PA9: J1.K8; also elsewhere on the board
PA10: J1.J8; also elsewhere on the board
PA13: J1.K10, J2.2; also elsewhere on the board
PA14: J1.J9, J2.3; also elsewhere on the board
PA15: J1.J10, J3.3; also elsewhere on the board
PA16: J1.C1; also elsewhere on the board
PA17: J1.E3; also elsewhere on the board
PA18: J1.D1; also elsewhere on the board
PA19: J1.E9, J3.2; also elsewhere on the board
PA20: J1.D8, J6.6; also elsewhere on the board
PA21: J1.D10, J6.7, R14.2; also elsewhere on the board
PA24: J1.C9; also elsewhere on the board
PA25: J1.B10; also elsewhere on the board
PA26: J1.J1; also elsewhere on the board
PA27: J1.H3; also elsewhere on the board
PA29: J1.J2; also elsewhere on the board
PA30: J1.K2; also elsewhere on the board
PA31: J1.J3; also elsewhere on the board
PB0: J1.A5; also elsewhere on the board
PB1: J1.B5; also elsewhere on the board
PB3: J1.A4; also elsewhere on the board
PB4: J1.D2; also elsewhere on the board
PB5: J1.C2; also elsewhere on the board
PB6: J1.H6; also elsewhere on the board
PB7: J1.K6; also elsewhere on the board
PB8: J1.J6; also elsewhere on the board
PB9: J1.K7; also elsewhere on the board
PB10: J1.G8; also elsewhere on the board
PB11: J1.H10; also elsewhere on the board
PB12: J1.H9, J3.5; also elsewhere on the board
PB13: J1.A7; also elsewhere on the board
PB14: J1.B7; also elsewhere on the board
PB15: J1.C6; also elsewhere on the board
PB16: J1.H7; also elsewhere on the board
PB17: J1.G10; also elsewhere on the board
PB18: D1.1 (K), J1.G9; also elsewhere on the board
PB19: J1.F9; also elsewhere on the board
PB20: J1.F10; also elsewhere on the board
PB21: J1.F8, J3.7; also elsewhere on the board
PB22: J1.E8, J3.8; also elsewhere on the board
PB23: J1.E10; also elsewhere on the board
PB24: J1.K3; also elsewhere on the board
PB25: J1.G3; also elsewhere on the board
PB26: J1.H4; also elsewhere on the board
PB27: J1.K4; also elsewhere on the board
PB28: J1.J4; also elsewhere on the board
PB29: J1.H5; also elsewhere on the board
PB30: J1.K5; also elsewhere on the board
PB31: J1.J5; also elsewhere on the board
PC1: J1.A10; also elsewhere on the board
PC2: J1.C8, J6.8; also elsewhere on the board
PC3: J1.A9; also elsewhere on the board
PC4: J1.B8, J6.9, R13.2; also elsewhere on the board
PC5: J1.A8; also elsewhere on the board
PC6: J1.C7, J6.10; also elsewhere on the board
PC7: J1.E2; also elsewhere on the board
PC8: J1.E1; also elsewhere on the board
PC9: J1.F3; also elsewhere on the board
PC10: J1.F1; also elsewhere on the board
PC11: J1.F2; also elsewhere on the board
PC12: J1.G1; also elsewhere on the board
PC13: J1.G2; also elsewhere on the board
PC14: J1.H1; also elsewhere on the board
PC15: J1.H2; also elsewhere on the board
PC18: J1.B4; also elsewhere on the board
PC25: J1.A6; also elsewhere on the board
PC26: J1.B6; also elsewhere on the board
VAA: J1.F5, J3.4; also elsewhere on the board
nRST: J1.C5, J2.7; also elsewhere on the board

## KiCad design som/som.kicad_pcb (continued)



Board: 4 copper layers, 25.4 x 38.1 mm, 68 parts (10 on the bottom side), 106 nets.

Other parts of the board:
kibuzzard-698ADC7E: G***; kibuzzard-698ADC7E
kibuzzard-698ADC8D: G***; kibuzzard-698ADC8D
kibuzzard-698ADC75: G***; kibuzzard-698ADC75
kibuzzard-698ADC83: G***; kibuzzard-698ADC83
kibuzzard-698ADC88: G***; kibuzzard-698ADC88
kibuzzard-698ADC92: G***; kibuzzard-698ADC92
kibuzzard-698ADC96: G***; kibuzzard-698ADC96
kibuzzard-698AE4C9: G***; kibuzzard-698AE4C9
kibuzzard-698CA76F: G***; kibuzzard-698CA76F

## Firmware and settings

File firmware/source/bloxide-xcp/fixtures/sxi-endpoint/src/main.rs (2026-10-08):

//! Host-only line driver for the real allocation-free SxI adapter and Session.
//! Its provider is a deterministic qualification fake, not the T11 LED owner.

use std::io::{self, BufRead, Write};
use xcp_core::{ProviderOperation, ProviderPort, ProviderRequest, Region, SubmitError, VirtualMap};
use xcp_messages::{
    ProviderCompletion, QuiesceResult, ReadData, ReadResult, RejectionReason, SynchronizeResult,
    WriteResult,
};
use xcp_sxi::{with_adapter, Adapter, AdapterEvent};

const BUILD_ID: [u8; 32] = [0xcd; 32];
const SCHEMA_ID: [u8; 32] = [0xab; 32];

#[derive(Default)]
struct Port {
    pending: Option<ProviderRequest>,
}

impl ProviderPort for Port {
    fn try_submit(&mut self, request: ProviderRequest) -> Result<(), SubmitError> {
        if self.pending.is_some() {
            Err(SubmitError::Busy)
        } else {
            self.pending = Some(request);
            Ok(())
        }
    }
}

struct Owner {
    period_ms: u16,
    duty_permille: u16,
    active_revision: u32,
    phase_us: u32,
    retained: Option<(ProviderOperation, WriteResult)>,
}

impl Owner {
    fn new() -> Self {
        Self {
            period_ms: 1000,
            duty_permille: 500,
            active_revision: 0,
            phase_us: 0x1234,
            retained: None,
        }
    }

    fn complete(&mut self, request: ProviderRequest) -> ProviderCompletion {
        match request {
            ProviderRequest::Synchronize { session_generation } => {
                ProviderCompletion::Synchronized {
                    session_generation,
                    result: SynchronizeResult::Ready { service_epoch: 1 },
                }
            }
            ProviderRequest::Read(request) => {
                let source = self.read_region(request.descriptor_id);
                let start = request.offset as usize;
                let end = start + request.length as usize;
                let mut bytes = [0; 7];
                let result = if end <= source.len() {
                    bytes[..request.length as usize].copy_from_slice(&source[start..end]);
                    ReadResult::Data(ReadData::new(bytes, request.length).unwrap())
                } else {
                    ReadResult::AccessDenied
                };
                ProviderCompletion::Read {
                    correlation: request.correlation,
                    result,
                }
            }
            ProviderRequest::Apply(request) => {
                let value =
                    u16::from_le_bytes([request.encoded_value[0], request.encoded_value[1]]);
                let (active, valid) = match request.descriptor_id {
                    2 => (&mut self.period_ms, (100..=10_000).contains(&value)),
                    3 => (&mut self.duty_permille, value <= 1000),
                    _ => {
                        let result = WriteResult::Rejected {
                            reason: RejectionReason::UnknownVariable,
                        };
                        self.retained = Some((request.operation, result));
                        return ProviderCompletion::Write {
                            correlation: request.operation.correlation(),
                            result,
                        };
                    }
                };
                let result = if valid {
                    let changed = *active != value;
                    if changed {
                        *active = value;
                        self.active_revision = self.active_revision.wrapping_add(1);
                        self.phase_us = self.phase_us.wrapping_add(1);
                    }
                    WriteResult::Applied {
                        changed,
                        active_revision: self.active_revision,
                    }
                } else {
                    WriteResult::Rejected {
                        reason: RejectionReason::Bounds,
                    }
                };
                self.retained = Some((request.operation, result));
                ProviderCompletion::Write {
                    correlation: request.operation.correlation(),
                    result,
                }
            }
            ProviderRequest::ResolveOrCancel { operation } => {
                let result = self
                    .retained
                    .filter(|(key, _)| *key == operation)
                    .map_or(WriteResult::Cancelled, |(_, result)| result);
                if self.retained.is_none() {
                    self.retained = Some((operation, result));
                }
                ProviderCompletion::Write {
                    correlation: operation.correlation(),
                    result,
                }
            }
            ProviderRequest::Quiesce { correlation } => ProviderCompletion::Quiesced {
                correlation,
                result: QuiesceResult::Quiesced,
            },
            ProviderRequest::ReleaseOutcome { operation } => {
                if self.retained.is_some_and(|(key, _)| key == operation) {
                    self.retained = None;
                }
                ProviderCompletion::Released {
                    correlation: operation.correlation(),
                }
            }
        }
    }

    fn read_region(&self, descriptor_id: u32) -> Vec<u8> {
        match descriptor_id {
            1 => [BUILD_ID.as_slice(), SCHEMA_ID.as_slice()].concat(),
            2 => self.period_ms.to_le_bytes().to_vec(),
            3 => self.duty_permille.to_le_bytes().to_vec(),
            4 => {
                let mut data = vec![0; 36];
                data[8..12].copy_from_slice(&self.active_revision.to_le_bytes());
                data[12..16].copy_from_slice(&self.phase_us.to_le_bytes());
                data[16..18].copy_from_slice(&self.period_ms.to_le_bytes());
                data[18..20].copy_from_slice(&self.duty_permille.to_le_bytes());
                data
            }
            _ => Vec::new(),
        }
    }
}

fn main() {
    let regions = [
        Region::read_only(1, 0, 64),
        Region::calibration(2, 0x1000, 2),
        Region::calibration(3, 0x1002, 2),
        Region::read_only(4, 0x2000, 36),
    ];
    let map = VirtualMap::new(&regions).unwrap();
    with_adapter(|mut adapter| {
        let mut port = Port::default();
        let mut owner = Owner::new();
        let mut drop_next_tx = false;

        for line in io::stdin().lock().lines() {
            let line = line.unwrap();
            let mut fields = line.split_whitespace();
            let command = fields.next().unwrap_or("");
            let now_us = fields
                .next()
                .and_then(|value| value.parse().ok())
                .unwrap_or(0);
            match command {
                "feed" => {
                    let bytes = fields.map(|value| u8::from_str_radix(value, 16).unwrap());
                    for byte in bytes {
                        let event = adapter.feed_byte(now_us, byte, &mut port);
                        println!("event {event:?}");
                    }
                    drive(
                        &mut adapter,
                        &map,
                        &mut port,
                        &mut owner,
                        now_us,
                        &mut drop_next_tx,
                    );
                }
                "poll" => {
                    println!("event {:?}", adapter.poll(now_us, &mut port));
                    drive(
                        &mut adapter,
                        &map,
                        &mut port,
                        &mut owner,
                        now_us,
                        &mut drop_next_tx,
                    );
                }
                "idle" => println!("event {:?}", adapter.observe_idle(now_us, &mut port)),
                "loss" | "stop" | "reset" => {
                    adapter.lifecycle_fence(now_us, &mut port);
                    println!("event LifecycleFence");
                }
                "uart-error" => println!("event {:?}", adapter.uart_error(now_us, &mut port)),
                "drop-next-tx" => {
                    drop_next_tx = true;
                    println!("event DropArmed");
                }
                "status" => println!(
                "status state={:?} epoch={} period={} duty={} revision={} phase={} retirement={}",
                adapter.session().state(),
                adapter.epoch(),
                owner.period_ms,
                owner.duty_permille,
                owner.active_revision,
                owner.phase_us,
                adapter.session().has_retirement(),
            ),
                "quit" => {
                    println!("done");
                    io::stdout().flush().unwrap();
                    break;
                }
                _ => println!("error unknown-command"),
            }
            println!("done");
            io::stdout().flush().unwrap();
        }
    });
}

fn drive(
    adapter: &mut Adapter,
    map: &VirtualMap<'_>,
    port: &mut Port,
    owner: &mut Owner,
    now_us: u64,
    drop_next_tx: &mut bool,
) {
    for _ in 0..16 {
        let event = if let Some(request) = port.pending.take() {
            println!("provider {request:?}");
            let completion = owner.complete(request);
            adapter.complete(completion, port)
        } else {
            adapter.service(map, now_us, port)
        };
        println!("event {event:?}");
        if event == AdapterEvent::ResponseQueued {
            let lease = adapter.take_tx().expect("queued response");
            if *drop_next_tx {
                println!("dropped {}", hex(lease.frame().as_slice()));
                *drop_next_tx = false;
            } else {
                assert!(adapter.lease_is_current(&lease));
                println!("tx {}", hex(lease.frame().as_slice()));
            }
            assert!(adapter.complete_tx(lease));
        }
        if matches!(
            event,
            AdapterEvent::Pending | AdapterEvent::Backpressured | AdapterEvent::Fenced(_)
        ) && port.pending.is_none()
        {
            break;
        }
    }
}

fn hex(bytes: &[u8]) -> String {
    bytes
        .iter()
        .map(|byte| format!("{byte:02x}"))
        .collect::<Vec<_>>()
        .join("")
}

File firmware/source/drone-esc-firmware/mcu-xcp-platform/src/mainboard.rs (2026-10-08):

//! Concrete I/O only. Policy and command state live in generated MainboardOwner.
use am13_rs::{io::{Mmio,RegisterIo},pwm};
use esc_som_board::{peripherals::{Analog,GateDrivers},pins::PWM_ROUTES};
use mainboard_characterization::{Hardware,HardwareError,Effective,ALL_MOTOR_SELECTOR,route_mask};
pub struct Board<I:RegisterIo=Mmio> {pub analog:Analog<I>,pub pwm:[pwm::Pwm<I>;4],pub drivers:GateDrivers<I>}
fn effective(e:pwm::Effective)->Effective {Effective{frequency:e.frequency_hz,high_ns:((e.high_ticks as u64*e.divider as u64*1_000_000_000+16_000_000)/32_000_000) as u32,period:e.period_ticks,high:e.high_ticks,divider:e.divider}}
fn route(channel:u16)->Result<(usize,u8),HardwareError>{PWM_ROUTES.get(channel as usize).map(|r|(r.2 as usize,r.3)).ok_or(HardwareError::Invalid)}
impl<I:RegisterIo> Hardware for Board<I> {
 fn start_quadrature(&mut self)->Result<[u32;4],HardwareError>{
  self.drivers.set_inl_enabled(false).map_err(|_|HardwareError::Transport)?;
  let result=(||{
   let pre=pwm::Pwm::quadrature_prepare(&mut self.pwm).map_err(|_|HardwareError::Transport)?;
   if self.faults()!=0 {return Err(HardwareError::Transport);}
   self.drivers.set_inl_enabled(true).map_err(|_|HardwareError::Transport)?;
   self.pwm[0].quadrature_release().map_err(|_|HardwareError::Transport)?;
   Ok(pre)
  })();
  if result.is_err(){self.stop();let _=self.enables(0);let _=self.pwm[0].quadrature_release();}
  result
 }
 fn adc_bounded(&mut self,c:usize)->Result<u16,HardwareError>{
  self.analog.capture(c,448,false,|_|{}).map(|v|v.raw).map_err(|_|HardwareError::Transport)
 }
 fn stop(&mut self){for p in &mut self.pwm{p.stop();}}
 fn configure(&mut self,c:u16,h:u32,d:u16)->Result<Effective,HardwareError>{
  self.stop();
  let result=(|| {
   let mask=route_mask(c);if mask==0 {return Err(HardwareError::Invalid);}
   let mut configured=0u8;let mut last=None;
   for (i,(_,_,m,o)) in PWM_ROUTES.iter().enumerate() {
    if mask&(1<<i)==0 {continue;}
    let p=&mut self.pwm[*m as usize];
    if configured&(1<<m)==0 {p.configure_frequency(h).map_err(|_|HardwareError::Invalid)?;configured|=1<<m;}
    let e=p.set_duty_permyriad(*o,d).map(effective).map_err(|_|HardwareError::Invalid)?;
    if last.is_some_and(|prior|prior!=e) {return Err(HardwareError::Invalid);}
    last=Some(e);
   }
   last.ok_or(HardwareError::Invalid)
  })();
  if result.is_err(){self.stop();}result
 }
 fn start(&mut self,c:u16)->Result<(),HardwareError>{
  let result=(|| {
   if c==ALL_MOTOR_SELECTOR {for p in &mut self.pwm {p.start().map_err(|_|HardwareError::Transport)?;}}
   else {let(m,_)=route(c)?;self.pwm[m].start().map_err(|_|HardwareError::Transport)?;}
   Ok(())
  })();
  if result.is_err(){self.stop();}result
 }
 fn pulse(&mut self,c:u16,n:u32)->Result<Effective,HardwareError>{let(m,o)=route(c)?;self.pwm[m].single_shot_ns(o,n).map(effective).map_err(|_|HardwareError::Invalid)}
 fn pulse_done(&mut self,c:u16)->bool{route(c).is_ok_and(|(m,_)|self.pwm[m].poll_single_shot())}
 fn enables(&mut self,mask:u16)->Result<(),HardwareError>{
  // Inhibit input gating first when disabling; keep enable assertions explicit.
  if mask==0 {
   // Independent inhibit paths: attempt both even if the first confirmation fails.
   let inl=self.drivers.set_inl_enabled(false);
   let drv=self.drivers.set_enabled(false);
   return if inl.is_ok() && drv.is_ok() {Ok(())}else{Err(HardwareError::Transport)};
  }
  self.drivers.set_inl_enabled(false).map_err(|_|HardwareError::Transport)?;
  self.drivers.set_enabled(mask&1!=0).map_err(|_|HardwareError::Transport)?;
  self.drivers.set_inl_enabled(mask&2!=0).map_err(|_|HardwareError::Transport)
 }
 fn transfer(&mut self,d:u16,f:u16)->Result<u16,HardwareError>{self.drivers.transfer(d as usize,f).map_err(|_|HardwareError::Transport)}
 fn adc(&mut self,c:usize)->Result<u16,HardwareError>{self.analog.read(c).map(|r|r.raw).map_err(|_|HardwareError::Transport)}
 fn diagnostic_sample(&mut self,c:u32,cycles:u32,mode:u32,offset:u32)->Result<mainboard_characterization::DiagnosticSample,HardwareError>{
  if c>3 || mode>1 {return Err(HardwareError::Invalid);}
  if mode==1 {self.pwm[0].adc_trigger_configure(offset).map_err(|_|HardwareError::Invalid)?;}
  let counters=[self.pwm[0].counter(),self.pwm[1].counter(),self.pwm[2].counter(),self.pwm[3].counter(),self.pwm[0].counter()];
  let pwm=&mut self.pwm[0];
  let raw=self.analog.capture([13,12,16,17][c as usize],cycles,mode==1,|on|pwm.adc_trigger_enable(on));
  let flags=if mode==1 {pwm.adc_trigger_flags()}else{0};let eoc=pwm.counter();
  let raw=raw.map_err(|_|HardwareError::Transport)?.raw;
  if mode==1 && flags&1==0 {return Err(HardwareError::Transport);}
  Ok(mainboard_characterization::DiagnosticSample{raw,counters,flags,eoc})
 }
 fn faults(&self)->u16{(0..4).fold(0,|v,i|v|if self.drivers.fault_asserted(i).unwrap_or(true){1<<i}else{0})}
}

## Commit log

2026-08-17 First formal review checkpoint
    [3.3V_Analog.kicad_sch, 5V_Buck.kicad_sch, M1_A.kicad_sch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]
2026-08-27 Initial layout completed
    [3.3V_Analog.kicad_sch, 5V_Buck.kicad_sch, M1_A.kicad_sch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]
2026-10-08 whitespace only fix (use DOS, not Unix CRLF)
    [mainboard_bom_with_mpns.csv, som_bom.csv]
2026-10-08 First proto hardware
    [M1_A.kicad_sch, M1_B.kicad_sch, M1_C.kicad_sch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]
2026-10-08 Add firmware
    [summary.csv]
2026-10-08 Add SWD flasher script
    [am13-jetson.cfg]
2026-10-08 docs: add Markdown hardware manuals and Pages CI
    [mainboard-analog-routes.csv, mainboard-connector-pads.csv, quadesc-gpio-map.csv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]
2026-10-13 docs: name the controller BeagleConnect Torque and add product brief
    Update module branding across the manuals and board illustrations. Complete the product brief from the PCB, schematics and TI specifications, include the Word brief, and identify production details r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
    Validation: documentation build and link checks passed; four-page Word brief rendered and visually reviewed; repository patch applies cleanly.
2026-10-15 docs: add XDS110 wiring and CCS workflow for BeagleConnect Torque
2026-10-15 docs: identify connector pin 1 in BeagleConnect Torque board views
2026-10-15 Refresh BeagleConnect QuadESC and BeagleConnect Torque schematic PDFs
2026-10-15 Automatically regenerate schematic PDFs with GitHub Actions
2026-10-15 Publish schematic PDFs as release assets and link from manuals
